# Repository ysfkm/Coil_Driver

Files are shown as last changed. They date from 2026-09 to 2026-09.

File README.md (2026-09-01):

# Coil Driver

## Summary
- Board hosting three independent bi-directional coil drivers (up to 3A each) off a shared +15V supply, using an H-bridge per channel for direction control.
- Setpoints for each channel's analog current control loop are set digitally over a backplane bus (address + data bits → DAC → analog loop); 4-layer 163mm x 100mm PCB.

## Specs
- **Input:** Digital Bus from backplane
  - A0~A7 as addresses
  - D9~D14 as data bits
- **Supply:** An external +15V with 10A rating and +15V from backplane
- **Output:** three bi-directional current up to 3A
- **Description:** Three separate coil drivers each capable of outputting 3A using the same +15V supply to output current. Utilizes digital interface from the backplane to set the setpoints for the analog current control loops separately and uses H-bridge to achieve bi-directional capability.
- **PCB:** 163mm x 100mm / 4 Layer

> **⚠ Note:** When setting a setpoint via the SPI lines, make sure the DIR bits are all driven to the right value since all DIR bits would be updated at the same time, not just the targeted channel for setpoint adjustment.

> **⚠ Note:** For the jumper selecting +15V power supply, make sure either ALL FOUR middle pins are connected or the LEFT AND RIGHT pins are connected, NEVER BOTH.

## Voltage / Nets

| Voltage / Nets | Purpose |
|---|---|
| +15V_EXT | External supply for driving large currents |
| +15V_BP | Backplane supply for regulating voltages and driving small currents |
| +15V | Jumper implemented to choose between +15V_EXT and +15V_BP<br>Drives main op-amp for current output<br>Drives MOSFETs to control H-bridge switching |
| +6V | Regulated from +15_BP, used to regulate +5VA |
| +5VA | Drives DAC and sensing op-amp. Used to generate VREF for DAC |
| +5V | Backplane supply to regulate +3V3 |
| +3V3 | Backplane supply for digital decoder |
| +3V3A | Regulated from +15V_BP, drives DAC |

## Modules

### Root page
- Backplane connector with digital bus, supply, and ground
- This board's own address switch
- Digital decoder latching the data bits when address from A0~A7 matches

### Power Supply page
- Several ferrite beads to connect different ground domains

### DAC
- Takes the three SPI lines and output 0~3V setpoint
- Has four channels, three used for each analog control loop
- Own regulator to precisely generate reference voltage (3V)

### Analog Control pages
All three are basically identical and have the following:
- Main op-amp driving the current
- Setpoint at main op-amp
- Compensator at main op-amp
- Current sense feedback network and voltage amplifier
- H-bridge
- MOSFET gate driver that drives the H-bridge based on DIR bit

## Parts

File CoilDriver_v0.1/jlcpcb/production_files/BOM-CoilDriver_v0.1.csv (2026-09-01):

Comment | Designator | Footprint | LCSC | Quantity
C113280 - SN74LVC573APWR | U17 | C113280-TSSOP-20_L6.5-W4.4-P0.65-LS6.4-BL | C113280 | 1
C114502 - M24C02-FDW | U14 | C114502-SOIC-8_L4.9-W3.9-P1.27-LS6.0-BL | C114502 | 1
10u 16V Tant | C20,C60 | C119051-CASE-A_3216 | C119051 | 2
10 1% | R30,R31,R43,R44,R6,R7 | R_0402_1005Metric | C138066 | 6
10n 50V X7R | C57,C63,C74 | C_0402_1005Metric | C15195 | 3
100p 50V C0G | C11,C23,C29,C37,C46,C67,C78,C8 | C_0402_1005Metric | C1546 | 8
C1554484-DAC8555IPW | U6 | C1554484-TSSOP-16_L5.0-W4.4-P0.65-LS6.4-TL | C1554484 | 1
C157411-LD29150DT50R | U7 | C157411-TO-252-3_L6.5-W5.8-P4.58-BL | C157411 | 1
6.8uH | L8 | C177249-IND-SMD_L5.4-W5.2_FXL0530 | C177249 | 1
C1855802-INA293B2IDBVR | U21,U25,U3 | C1855802-SOT-23-5_L2.9-W1.6-P0.95-LS2.8-BR | C1855802 | 3
C2071868-AP63200WU-7 | U10,U11 | C2071868-SOT-23-6_L2.9-W1.6-P0.95-LS2.8-BR | C2071868 | 2
C207245-SD15C-01FTG | U5 | C207245-SOD-323_L1.7-W1.3-LS2.5-BI-1 | C207245 | 1
22n C0G | C6,C64,C75 | C_0805_2012Metric | C2181592 | 3
C22461594 - PCF8574AP | U15 | C22461594-TSSOP-16_L5.0-W4.4-P0.65-LS6.4-BL-1 | C22461594 | 1
22uH >0.5A | L3,L7 | L_1812_4532Metric | C22469096 | 2
C22469958 - 74LVC1GU04 | U16 | C22469958-SOT-353-5_L2.1-W1.3-P0.65-LS2.3-BL | C22469958 | 1
100 1% | R9 | R_0402_1005Metric | C25076 | 1
R33_Pack | RN3,RN4 | C25508-RES-ARRAY-SMD_0603-8P-L3.2-W1.6-BL | C25508 | 2
C259972-LM1084S-3.3_TR | U20 | C259972-TO-263-3_L8.6-W10.2-P2.54-LS14.4-TL | C259972 | 1
C2653336-74FCT521CTSOG8 | U13 | C2653336-SOIC127P1032X265-20N | C2653336 | 1
C2687965-OPA548FKTWT | U1,U22,U26 | C2687965-TO-263-7_L10.2-W8.9-P1.27-LS15.2-BL | C2687965 | 3
100u 35V Alum | C16 | C2887272-CAP-SMD_BD6.3-L6.6-W6.6-LS7.2-FD_3 | C2887272 | 1
10k 1% | R1,R10,R15,R16,R17,R2,R24,R26,R37,R39,R8 | R_0402_1005Metric | C2906861 | 11
1k 5% | R18,R19,R20,R21,R33,R34,R35,R36,R46,R47,R48,R49 | R_0402_1005Metric | C2906899 | 12
30k 1% | R12 | R_0402_1005Metric | C2909347 | 1
62k 1% | R13 | R_0402_1005Metric | C2909375 | 1
C29718-R10k_Pack04 | RN1,RN2 | C29718-RES-ARRAY-SMD_0603-8P-L3.2-W1.6-BL | C29718 | 2
196k 1% | R11,R14 | R_0402_1005Metric | C3013157 | 2
453k 1% | R28,R4,R41 | R_0402_1005Metric | C3013172 | 3
10u 25V X7R | C10,C13,C19,C2,C21,C3,C30,C32,C33,C34,C40,C41,C42,C43,C49,C58,C68,C70,C71,C79,C81,C82 | C_0805_2012Metric | C3039694 | 22
C306220-826925-6 | J3 | C306220-CONN-TH_12P-P2.54_826925-6 | C306220 | 1
100n 50V X7R | C1,C12,C17,C18,C22,C24,C27,C28,C35,C36,C44,C45,C50,C51,C52,C54,C59,C61,C66,C69,C77,C80,C9 | C_0402_1005Metric | C307331 | 23
1n 50V C0G | C26 | C_0402_1005Metric | C307441 | 1
4k02 1% | R22,R25,R38 | R_0402_1005Metric | C324800 | 3
C3697-WJ2EDGRC-5.08-02P-14-00A | CN1,CN3,CN5,CN7 | C3697-CONN-TH_2P-P5.08_WJ2EDGRC-5.08-2P | C3697 | 4
100u 16V Alum | C31 | C37308-CAP-SMD_BD6.3-L6.6-W6.6-LS7.2-FD | C37308 | 1
2200u 35V Alum | C15,C4,C72,C83 | C3829879-CAP-SMD_BD16.0-L17.0-W17.0-LS18.0-FD | C3829879 | 4
C458084-DS-08RP | SW1 | C458084-SW-TH_DS-08RP | C458084 | 1
Conn_01x02 | J2 | C492401-HDR-TH_2P-P2.54-V-M | C492401 | 1
C506609-SISS27DN-T1-GE3 | U2 | C506609-POWERPAK-1212-8_L3.3-W3.3-P0.65-BL-EP | C506609 | 1
C50793 - NC7WZ14P6X | U12 | C50793-SC-70-6_L2.2-W1.3-P0.65-LS2.2-BR | C50793 | 1
C511854-SS54SMB | D1,D10,D11,D12,D13,D14,D15,D2,D3,D4,D5,D6,D7,D8,D9 | C511854-SMB_L4.6-W3.6-LS5.3-RD | C511854 | 15
C5173361-DIN41612-CONN-TH_96P | J1 | C5173361-DIN41612-96P | C5173361 | 1
33uH | L2 | L_0603_1608Metric | C5339211 | 1
10uH | L5 | C540965-IND-SMD_L6.5-W6.5_VISHAY | C540965 | 1
C550069-BZB784-C15,115 | U23,U27,U4 | C550069-SOT-323-3_L2.0-W1.3-P1.30-LS2.1-BR | C550069 | 3
C637542-MIC4428YM | U19,U24,U28 | C637542-SOIC-8_L4.9-W3.9-P1.27-LS6.0-BL | C637542 | 3
C659573-ADR443BRZ-REEL7 | U8 | C659573-SOIC-8_L4.9-W3.9-P1.27-LS6.0-BL | C659573 | 1
C71370-WJ2EDGK-5.08-02P-14-00A | CN2,CN4,CN6,CN8 | C71370-FL_001 | C71370 | 4
C7220836-BSC010N04LS6ATMA1 | T1,T10,T11,T12,T2,T3,T4,T5,T6,T7,T8,T9 | C7220836-TDSON-8_L6.0-W5.0-P1.27-LS6.2-BL_1 | C7220836 | 12
3.3u 25V X7R | C65,C7,C76 | C_0805_2012Metric | C7393948 | 3
0.02 1W 1% | R32,R45,R5 | R_1206_3216Metric | C7420010 | 3
22u 16V X7R | C38,C39 | C_1206_3216Metric | C7472972 | 2
1u 10V X7R | C25,C53,C55,C56 | C_0402_1005Metric | C7500381 | 4
C7835-SN74LVC1G14DBVR | U18 | C7835-SOT-23-5_L3.0-W1.7-P0.95-LS2.8-BR | C7835 | 1
22uH | L6,L9 | C842901-IND-SMD_L7.0-W6.6 | C842901 | 2
C85832-BLM18KG331SN1D | L1,L10,L4 | C85832-L0603 | C85832 | 3
15p 50V C0G | C14 | C_0402_1005Metric | C880657 | 1
C907854-SD12C | U9 | C907854-SOD-323_L1.7-W1.3-LS2.5-BI | C907854 | 1
22u 10V X7R | C47,C48 | C_0805_2012Metric | C907991 | 2
C965863-XL-1606UGC | D29 | C965863-LED-SMD_L1.7-W1.1-R-RD_ORANGE | C965863 | 1

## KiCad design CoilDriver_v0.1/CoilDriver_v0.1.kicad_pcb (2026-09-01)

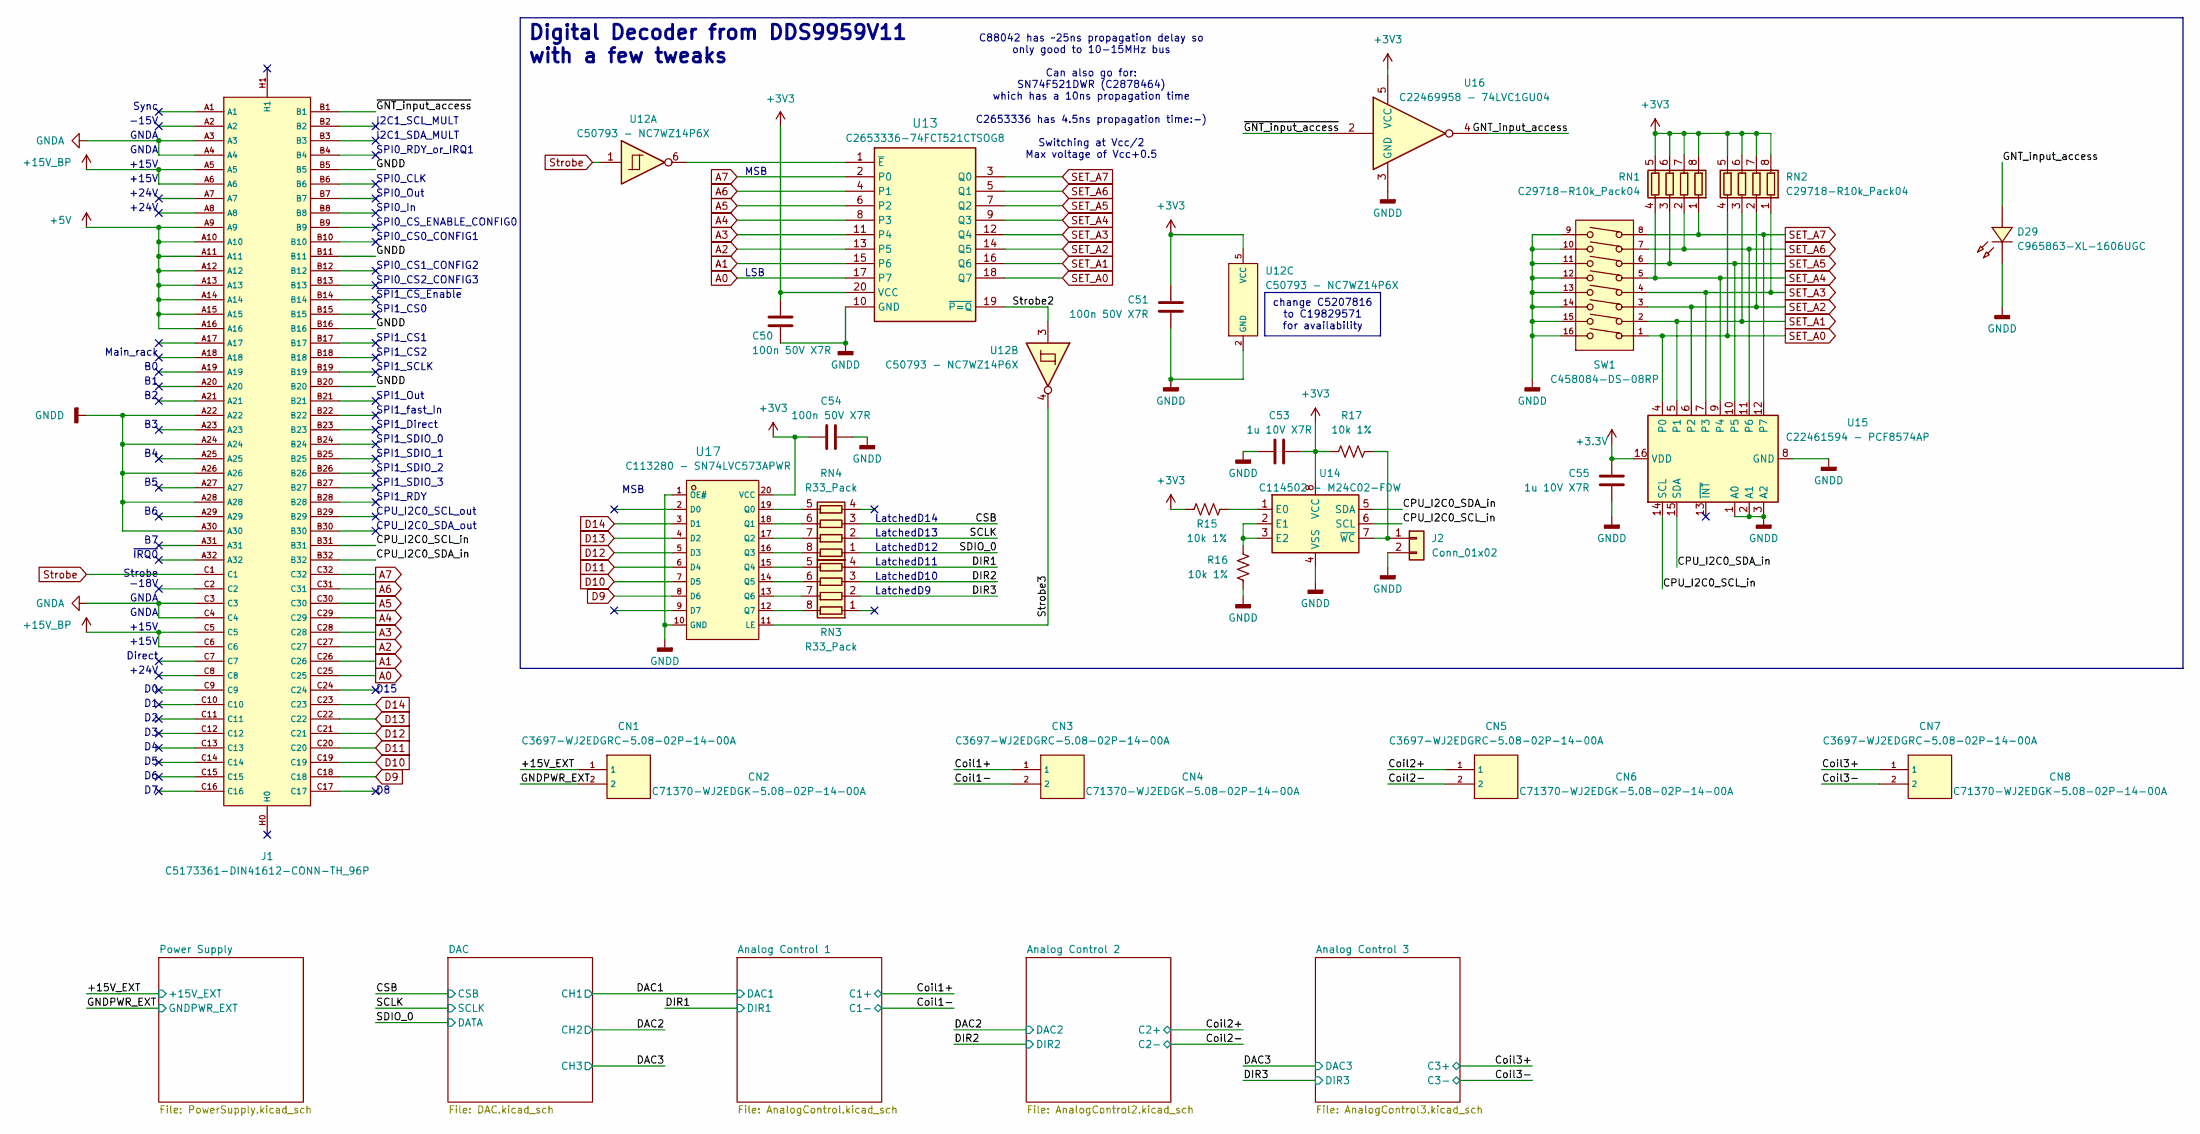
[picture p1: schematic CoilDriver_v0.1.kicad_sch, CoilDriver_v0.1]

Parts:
C50, C51, C54: 100n 50V X7R; C_0402_1005Metric; LCSC C307331
C53, C55: 1u 10V X7R; C_0402_1005Metric; LCSC C7500381
CN1, CN3, CN5, CN7: C3697-WJ2EDGRC-5.08-02P-14-00A; C3697-CONN-TH_2P-P5.08_WJ2EDGRC-5.08-2P; LCSC C3697
CN2, CN4, CN6, CN8: C71370-WJ2EDGK-5.08-02P-14-00A; C71370-FL_001; LCSC C71370
D29: C965863-XL-1606UGC; C965863-LED-SMD_L1.7-W1.1-R-RD_ORANGE; LCSC C965863
J1: C5173361-DIN41612-CONN-TH_96P; C5173361-DIN41612-96P; LCSC C5173361
J2: Conn_01x02; C492401-HDR-TH_2P-P2.54-V-M; LCSC C492401
R15, R16, R17: 10k 1%; R_0402_1005Metric; LCSC C2906861
RN1, RN2: C29718-R10k_Pack04; C29718-RES-ARRAY-SMD_0603-8P-L3.2-W1.6-BL; LCSC C29718
RN3, RN4: R33_Pack; C25508-RES-ARRAY-SMD_0603-8P-L3.2-W1.6-BL; LCSC C25508
SW1: C458084-DS-08RP; C458084-SW-TH_DS-08RP; LCSC C458084
U12: C50793 - NC7WZ14P6X; C50793-SC-70-6_L2.2-W1.3-P0.65-LS2.2-BR; LCSC C50793
U13: C2653336-74FCT521CTSOG8; C2653336-SOIC127P1032X265-20N; LCSC C2653336
U14: C114502 - M24C02-FDW; C114502-SOIC-8_L4.9-W3.9-P1.27-LS6.0-BL; LCSC C114502
U15: C22461594 - PCF8574AP; C22461594-TSSOP-16_L5.0-W4.4-P0.65-LS6.4-BL-1; LCSC C22461594
U16: C22469958 - 74LVC1GU04; C22469958-SOT-353-5_L2.1-W1.3-P0.65-LS2.3-BL; LCSC C22469958
U17: C113280 - SN74LVC573APWR; C113280-TSSOP-20_L6.5-W4.4-P0.65-LS6.4-BL; LCSC C113280

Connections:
+3.3V: C55.1, U15.16 (VDD)
+3V3: C50.1, C51.1, C53.1, C54.1, R15.1, R17.1, RN1.5 (R4.2), RN1.6 (R3.2), RN1.7 (R2.2), RN1.8 (R1.2), RN2.5 (R4.2), RN2.6 (R3.2), RN2.7 (R2.2), RN2.8 (R1.2), U12.5 (VCC), U13.20 (VCC), U14.8 (VCC), U16.5 (VCC), U17.20 (VCC); also elsewhere on the board
+5V: J1.A9, J1.A10, J1.A11, J1.A12, J1.A13, J1.A14, J1.A15, J1.A16; also elsewhere on the board
+15V_BP: J1.A5, J1.A6, J1.C5, J1.C6; also elsewhere on the board
/+15V_EXT: CN1.1; also elsewhere on the board
/CPU_I2C0_SCL_in: J1.B31, U14.6 (SCL), U15.14 (SCL)
/CPU_I2C0_SDA_in: J1.B32, U14.5 (SDA), U15.15 (SDA)
/CSB: RN4.3 (R3.1); also elsewhere on the board
/Coil1+: CN3.1; also elsewhere on the board
/Coil1-: CN3.2; also elsewhere on the board
/Coil2+: CN5.1; also elsewhere on the board
/Coil2-: CN5.2; also elsewhere on the board
/Coil3+: CN7.1; also elsewhere on the board
/Coil3-: CN7.2; also elsewhere on the board
/DIR1: RN3.4 (R4.1); also elsewhere on the board
/DIR2: RN3.3 (R3.1); also elsewhere on the board
/DIR3: RN3.2 (R2.1); also elsewhere on the board
/GNT_input_access: D29.2 (A), U16.4
/SCLK: RN4.2 (R2.1); also elsewhere on the board
/SDIO_0: RN4.1 (R1.1); also elsewhere on the board
/Strobe2: U12.3, U13.19 (~P=Q)
/Strobe3: U12.4, U17.11 (LE)
/~GNT_input_access: J1.B1, U16.2
A0: J1.C25, U13.17 (P7)
A1: J1.C26, U13.15 (P6)
A2: J1.C27, U13.13 (P5)
A3: J1.C28, U13.11 (P4)
A4: J1.C29, U13.8 (P3)
A5: J1.C30, U13.6 (P2)
A6: J1.C31, U13.4 (P1)
A7: J1.C32, U13.2 (P0)
D9: J1.C18, U17.8 (D6)
D10: J1.C19, U17.7 (D5)
D11: J1.C20, U17.6 (D4)
D12: J1.C21, U17.5 (D3)
D13: J1.C22, U17.4 (D2)
D14: J1.C23, U17.3 (D1)
GNDA: J1.A3, J1.A4, J1.C3, J1.C4; also elsewhere on the board
GNDD: C50.2, C51.2, C53.2, C54.2, C55.2, D29.1 (K), J1.A22, J1.A24, J1.A26, J1.A28, J1.A30, J1.B5, J1.B11, J1.B16, J1.B20, J2.2, R16.2, SW1.9, SW1.10, SW1.11, SW1.12, SW1.13, SW1.14, SW1.15, SW1.16, U12.2 (GND), U13.10 (GND), U14.4 (VSS), U15.1 (A0), U15.2 (A1), U15.3 (A2), U15.8 (GND), U16.3 (GND), U17.1 (OE#), U17.10 (GND); also elsewhere on the board
GNDPWR: CN1.2; also elsewhere on the board
unnamed: J2.1, R17.2, U14.7 (~WC)
unnamed: RN3.8 (R1.2), U17.12 (Q7)
unnamed: RN3.7 (R2.2), U17.13 (Q6)
unnamed: RN3.6 (R3.2), U17.14 (Q5)
unnamed: RN3.5 (R4.2), U17.15 (Q4)
unnamed: RN4.8 (R1.2), U17.16 (Q3)
unnamed: RN4.7 (R2.2), U17.17 (Q2)
unnamed: RN4.6 (R3.2), U17.18 (Q1)
unnamed: RN4.5 (R4.2), U17.19 (Q0)
unnamed: U12.6, U13.1 (~E)
unnamed: R15.2, U14.1 (E0)
unnamed: R16.1, U14.2 (E1), U14.3 (E2)
SET_A0: RN2.4 (R4.1), SW1.1, U13.18 (Q7), U15.4 (P0)
SET_A1: RN2.3 (R3.1), SW1.2, U13.16 (Q6), U15.5 (P1)
SET_A2: RN2.2 (R2.1), SW1.3, U13.14 (Q5), U15.6 (P2)
SET_A3: RN2.1 (R1.1), SW1.4, U13.12 (Q4), U15.7 (P3)
SET_A4: RN1.4 (R4.1), SW1.5, U13.9 (Q3), U15.9 (P4)
SET_A5: RN1.3 (R3.1), SW1.6, U13.7 (Q2), U15.10 (P5)
SET_A6: RN1.2 (R2.1), SW1.7, U13.5 (Q1), U15.11 (P6)
SET_A7: RN1.1 (R1.1), SW1.8, U13.3 (Q0), U15.12 (P7)
Strobe: J1.C1, U12.1

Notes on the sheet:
Main_rack
CPU_I2C0_SCL_out
SPI1_Direct
SPI0_CS2_CONFIG3
+24V
SPI0_CS_ENABLE_CONFIG0
+15V
SPI0_In
LatchedD14
Strobe
SPI1_CS1
SPI1_SCLK
SPI1_SDIO_2
SPI1_SDIO_3
SPI1_Out
Direct
GNDA
-18V
SPI1_SDIO_1
LatchedD11
CPU_I2C0_SDA_out
MSB
Sync
~{IRQ0}
LatchedD9
SPI0_CLK
D15
SPI0_Out
LSB
LatchedD10
SPI0_CS1_CONFIG2
SPI1_CS0
LatchedD13
SPI1_CS2
~{SPI1_CS_Enable}
SPI0_RDY_or_IRQ1
C88042 has ~25ns propagation delay so only good to 10-15MHz bus Can also go for: SN74F521DWR (C2878464) which has a 10ns propagation time C2653336 has 4.5ns propagation time:-) Switching at Vcc/2 Max voltage of Vcc+0.5
I2C1_SCL_MULT
I2C1_SDA_MULT
SPI1_SDIO_0

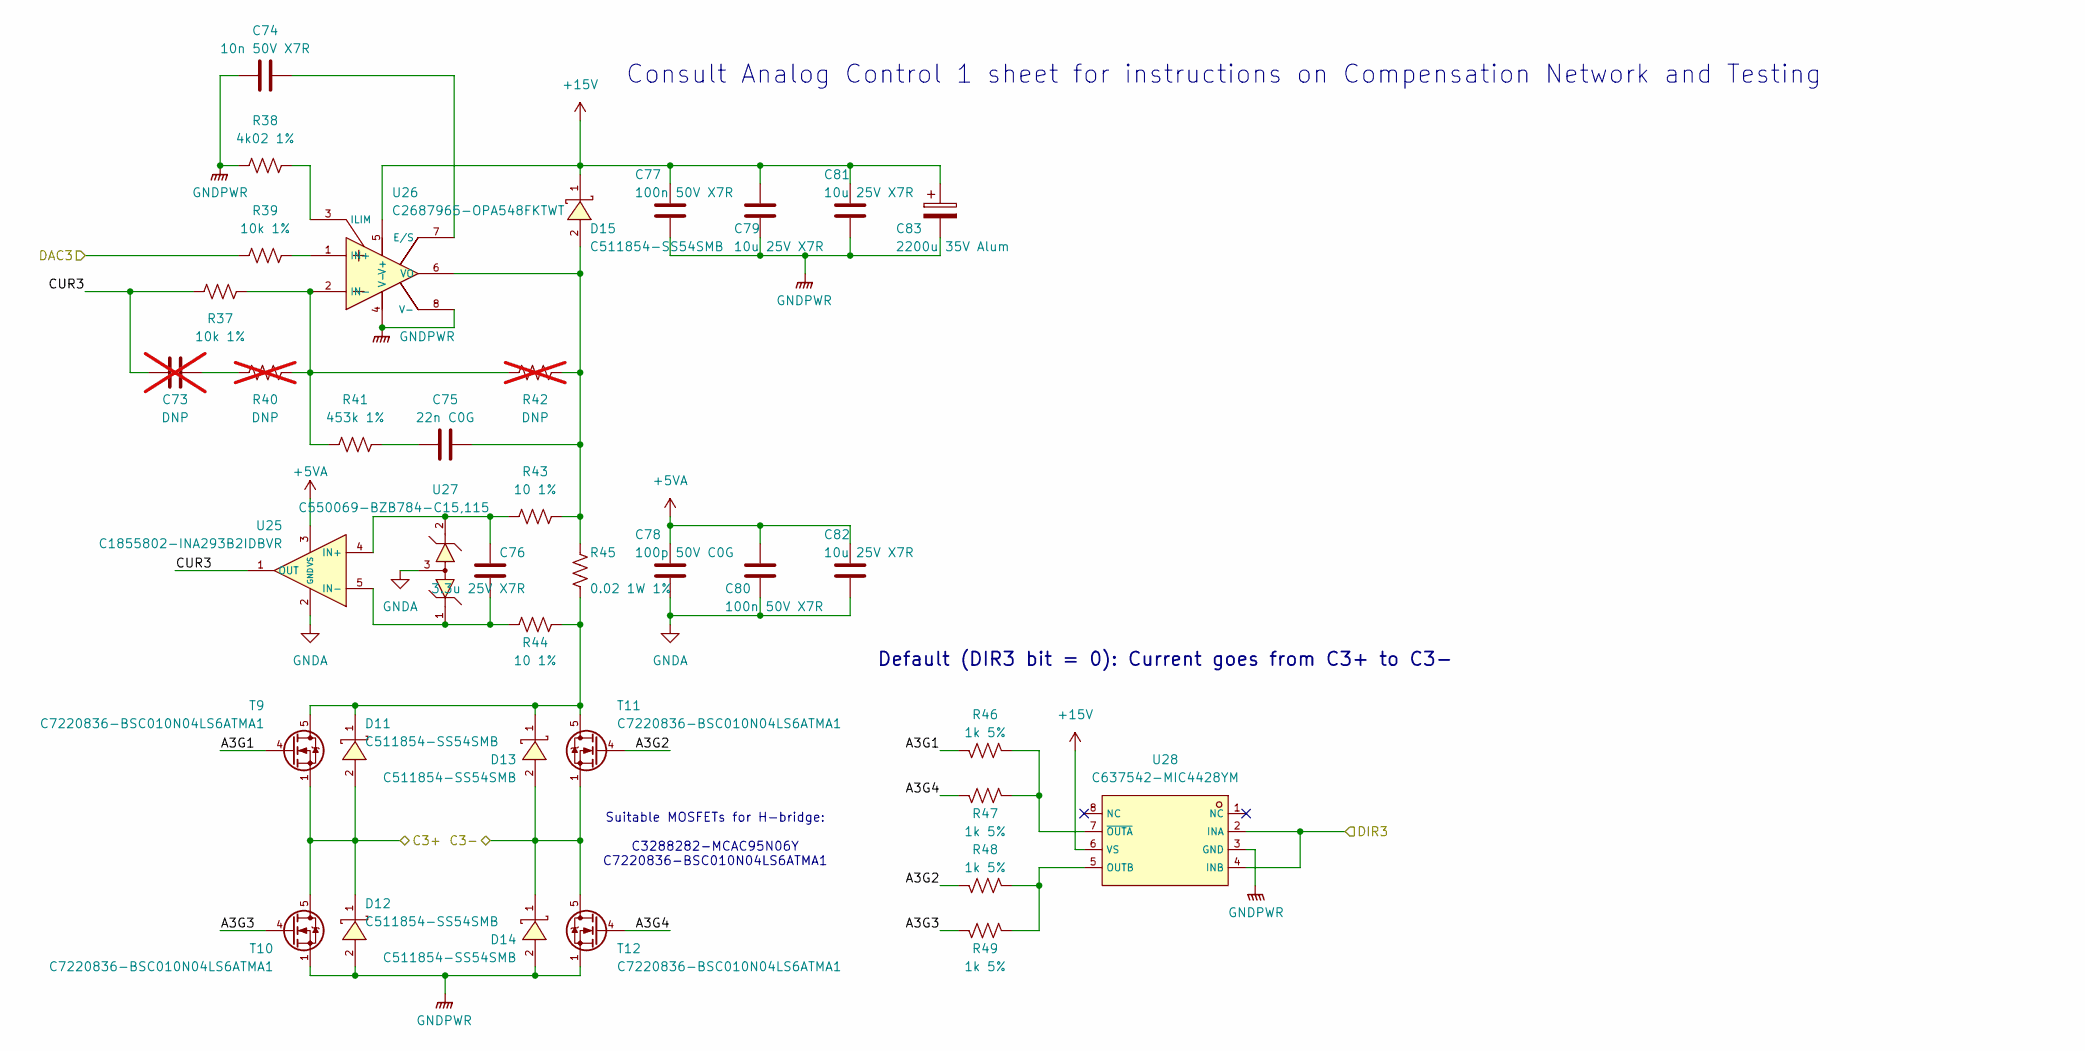
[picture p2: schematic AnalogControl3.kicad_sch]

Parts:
C73: DNP; C_0805_2012Metric; not fitted
C74: 10n 50V X7R; C_0402_1005Metric; LCSC C15195
C75: 22n C0G; C_0805_2012Metric; LCSC C2181592
C76: 3.3u 25V X7R; C_0805_2012Metric; LCSC C7393948
C77, C80: 100n 50V X7R; C_0402_1005Metric; LCSC C307331
C78: 100p 50V C0G; C_0402_1005Metric; LCSC C1546
C79, C81, C82: 10u 25V X7R; C_0805_2012Metric; LCSC C3039694
C83: 2200u 35V Alum; C3829879-CAP-SMD_BD16.0-L17.0-W17.0-LS18.0-FD; LCSC C3829879
D11, D12, D13, D14, D15: C511854-SS54SMB; C511854-SMB_L4.6-W3.6-LS5.3-RD; LCSC C511854
R37, R39: 10k 1%; R_0402_1005Metric; LCSC C2906861
R38: 4k02 1%; R_0402_1005Metric; LCSC C324800
R40, R42: DNP; R_0603_1608Metric; not fitted
R41: 453k 1%; R_0402_1005Metric; LCSC C3013172
R43, R44: 10 1%; R_0402_1005Metric; LCSC C138066
R45: 0.02 1W 1%; R_1206_3216Metric; LCSC C7420010
R46, R47, R48, R49: 1k 5%; R_0402_1005Metric; LCSC C2906899
T9, T10, T11, T12: C7220836-BSC010N04LS6ATMA1; C7220836-TDSON-8_L6.0-W5.0-P1.27-LS6.2-BL_1; LCSC C7220836
U25: C1855802-INA293B2IDBVR; C1855802-SOT-23-5_L2.9-W1.6-P0.95-LS2.8-BR; LCSC C1855802
U26: C2687965-OPA548FKTWT; C2687965-TO-263-7_L10.2-W8.9-P1.27-LS15.2-BL; LCSC C2687965
U27: C550069-BZB784-C15,115; C550069-SOT-323-3_L2.0-W1.3-P1.30-LS2.1-BR; LCSC C550069
U28: C637542-MIC4428YM; C637542-SOIC-8_L4.9-W3.9-P1.27-LS6.0-BL; LCSC C637542

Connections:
+5VA: C78.1, C80.1, C82.1, U25.3 (VS); also elsewhere on the board
+15V: C77.1, C79.1, C81.1, C83.1, D15.1 (K), U26.5 (V+), U28.6 (VS); also elsewhere on the board
/Analog Control 3/A3G1: R46.2, T9.4 (G)
/Analog Control 3/A3G2: R48.2, T11.4 (G)
/Analog Control 3/A3G3: R49.2, T10.4 (G)
/Analog Control 3/A3G4: R47.2, T12.4 (G)
/Analog Control 3/CUR3: C73.1, R37.1, U25.1 (OUT)
/Coil3+: D11.2 (A), D12.1 (K), T9.1 (S), T10.5 (D); also elsewhere on the board
/Coil3-: D13.2 (A), D14.1 (K), T11.1 (S), T12.5 (D); also elsewhere on the board
/DAC3: R39.1; also elsewhere on the board
/DIR3: U28.2 (INA), U28.4 (INB); also elsewhere on the board
GNDA: C78.2, C80.2, C82.2, U25.2 (GND), U27.3; also elsewhere on the board
GNDPWR: C74.1, C77.2, C79.2, C81.2, C83.2, D12.2 (A), D14.2 (A), R38.1, T10.1 (S), T12.1 (S), U26.4 (V-), U26.8 (V-), U28.3 (GND); also elsewhere on the board
unnamed: C73.2, R40.1
unnamed: C75.1, R41.2
unnamed: D11.1 (K), D13.1 (K), R44.1, R45.1, T9.5 (D), T11.5 (D)
unnamed: C75.2, D15.2 (A), R42.2, R43.1, R45.2, U26.6 (VO)
unnamed: C76.2, R43.2, U25.4 (IN+), U27.2
unnamed: C76.1, R44.2, U25.5 (IN-), U27.1
unnamed: C74.2, U26.7 (E/S)
unnamed: R38.2, U26.3 (ILIM)
unnamed: R39.2, U26.1 (IN+)
unnamed: R37.2, R40.2, R41.1, R42.1, U26.2 (IN-)
unnamed: R48.1, R49.1, U28.5 (OUTB)
unnamed: R46.1, R47.1, U28.7 (~OUTA)

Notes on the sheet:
Consult Analog Control 1 sheet for instructions on Compensation Network and Testing
Default (DIR3 bit = 0): Current goes from C3+ to C3-
Suitable MOSFETs for H-bridge: C3288282-MCAC95N06Y C7220836-BSC010N04LS6ATMA1

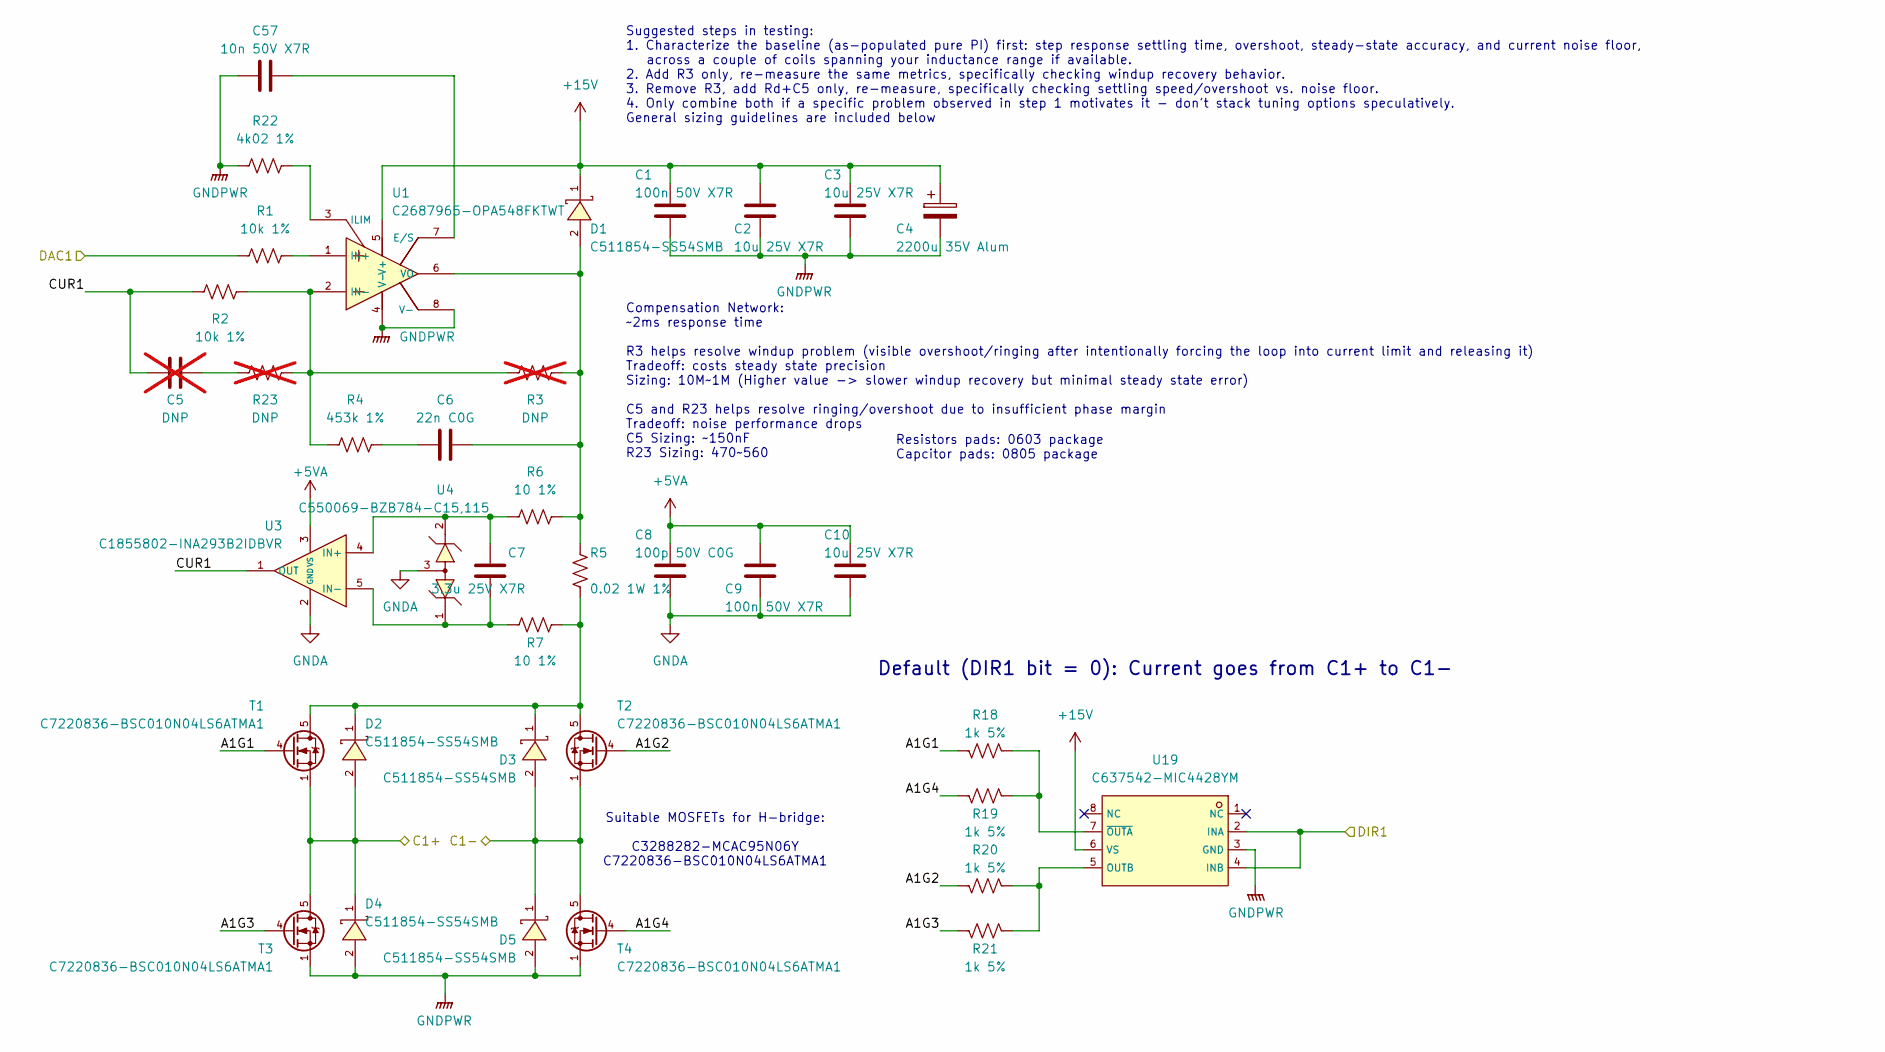
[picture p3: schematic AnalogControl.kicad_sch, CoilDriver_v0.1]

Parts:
C1, C9: 100n 50V X7R; C_0402_1005Metric; LCSC C307331
C2, C3, C10: 10u 25V X7R; C_0805_2012Metric; LCSC C3039694
C4: 2200u 35V Alum; C3829879-CAP-SMD_BD16.0-L17.0-W17.0-LS18.0-FD; LCSC C3829879
C5: DNP; C_0805_2012Metric; not fitted
C6: 22n C0G; C_0805_2012Metric; LCSC C2181592
C7: 3.3u 25V X7R; C_0805_2012Metric; LCSC C7393948
C8: 100p 50V C0G; C_0402_1005Metric; LCSC C1546
C57: 10n 50V X7R; C_0402_1005Metric; LCSC C15195
D1, D2, D3, D4, D5: C511854-SS54SMB; C511854-SMB_L4.6-W3.6-LS5.3-RD; LCSC C511854
R1, R2: 10k 1%; R_0402_1005Metric; LCSC C2906861
R3, R23: DNP; R_0603_1608Metric; not fitted
R4: 453k 1%; R_0402_1005Metric; LCSC C3013172
R5: 0.02 1W 1%; R_1206_3216Metric; LCSC C7420010
R6, R7: 10 1%; R_0402_1005Metric; LCSC C138066
R18, R19, R20, R21: 1k 5%; R_0402_1005Metric; LCSC C2906899
R22: 4k02 1%; R_0402_1005Metric; LCSC C324800
T1, T2, T3, T4: C7220836-BSC010N04LS6ATMA1; C7220836-TDSON-8_L6.0-W5.0-P1.27-LS6.2-BL_1; LCSC C7220836
U1: C2687965-OPA548FKTWT; C2687965-TO-263-7_L10.2-W8.9-P1.27-LS15.2-BL; LCSC C2687965
U3: C1855802-INA293B2IDBVR; C1855802-SOT-23-5_L2.9-W1.6-P0.95-LS2.8-BR; LCSC C1855802
U4: C550069-BZB784-C15,115; C550069-SOT-323-3_L2.0-W1.3-P1.30-LS2.1-BR; LCSC C550069
U19: C637542-MIC4428YM; C637542-SOIC-8_L4.9-W3.9-P1.27-LS6.0-BL; LCSC C637542

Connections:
+5VA: C8.1, C9.1, C10.1, U3.3 (VS); also elsewhere on the board
+15V: C1.1, C2.1, C3.1, C4.1, D1.1 (K), U1.5 (V+), U19.6 (VS); also elsewhere on the board
/Analog Control 1/A1G1: R18.2, T1.4 (G)
/Analog Control 1/A1G2: R20.2, T2.4 (G)
/Analog Control 1/A1G3: R21.2, T3.4 (G)
/Analog Control 1/A1G4: R19.2, T4.4 (G)
/Analog Control 1/CUR1: C5.1, R2.1, U3.1 (OUT)
/Coil1+: D2.2 (A), D4.1 (K), T1.1 (S), T3.5 (D); also elsewhere on the board
/Coil1-: D3.2 (A), D5.1 (K), T2.1 (S), T4.5 (D); also elsewhere on the board
/DAC1: R1.1; also elsewhere on the board
/DIR1: U19.2 (INA), U19.4 (INB); also elsewhere on the board
GNDA: C8.2, C9.2, C10.2, U3.2 (GND), U4.3; also elsewhere on the board
GNDPWR: C1.2, C2.2, C3.2, C4.2, C57.1, D4.2 (A), D5.2 (A), R22.1, T3.1 (S), T4.1 (S), U1.4 (V-), U1.8 (V-), U19.3 (GND); also elsewhere on the board
unnamed: C5.2, R23.1
unnamed: C6.1, R4.2
unnamed: C6.2, D1.2 (A), R3.2, R5.2, R6.1, U1.6 (VO)
unnamed: D2.1 (K), D3.1 (K), R5.1, R7.1, T1.5 (D), T2.5 (D)
unnamed: C57.2, U1.7 (E/S)
unnamed: R22.2, U1.3 (ILIM)
unnamed: R1.2, U1.1 (IN+)
unnamed: R2.2, R3.1, R4.1, R23.2, U1.2 (IN-)
unnamed: C7.2, R6.2, U3.4 (IN+), U4.2
unnamed: C7.1, R7.2, U3.5 (IN-), U4.1
unnamed: R20.1, R21.1, U19.5 (OUTB)
unnamed: R18.1, R19.1, U19.7 (~OUTA)

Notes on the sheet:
Default (DIR1 bit = 0): Current goes from C1+ to C1-
Suitable MOSFETs for H-bridge: C3288282-MCAC95N06Y C7220836-BSC010N04LS6ATMA1
Suggested steps in testing: 1. Characterize the baseline (as-populated pure PI) first: step response settling time, overshoot, steady-state accuracy, and current noise floor, across a couple of coils spanning your inductance range if available. 2. Add R3 only, re-measure the same metrics, specifica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
Compensation Network: ~2ms response time R3 helps resolve windup problem (visible overshoot/ringing after intentionally forcing the loop into current limit and releasing it) Tradeoff: costs steady state precision Sizing: 10M~1M (Higher value -> slower windup recovery but minimal steady state error)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
Resistors pads: 0603 package Capcitor pads: 0805 package

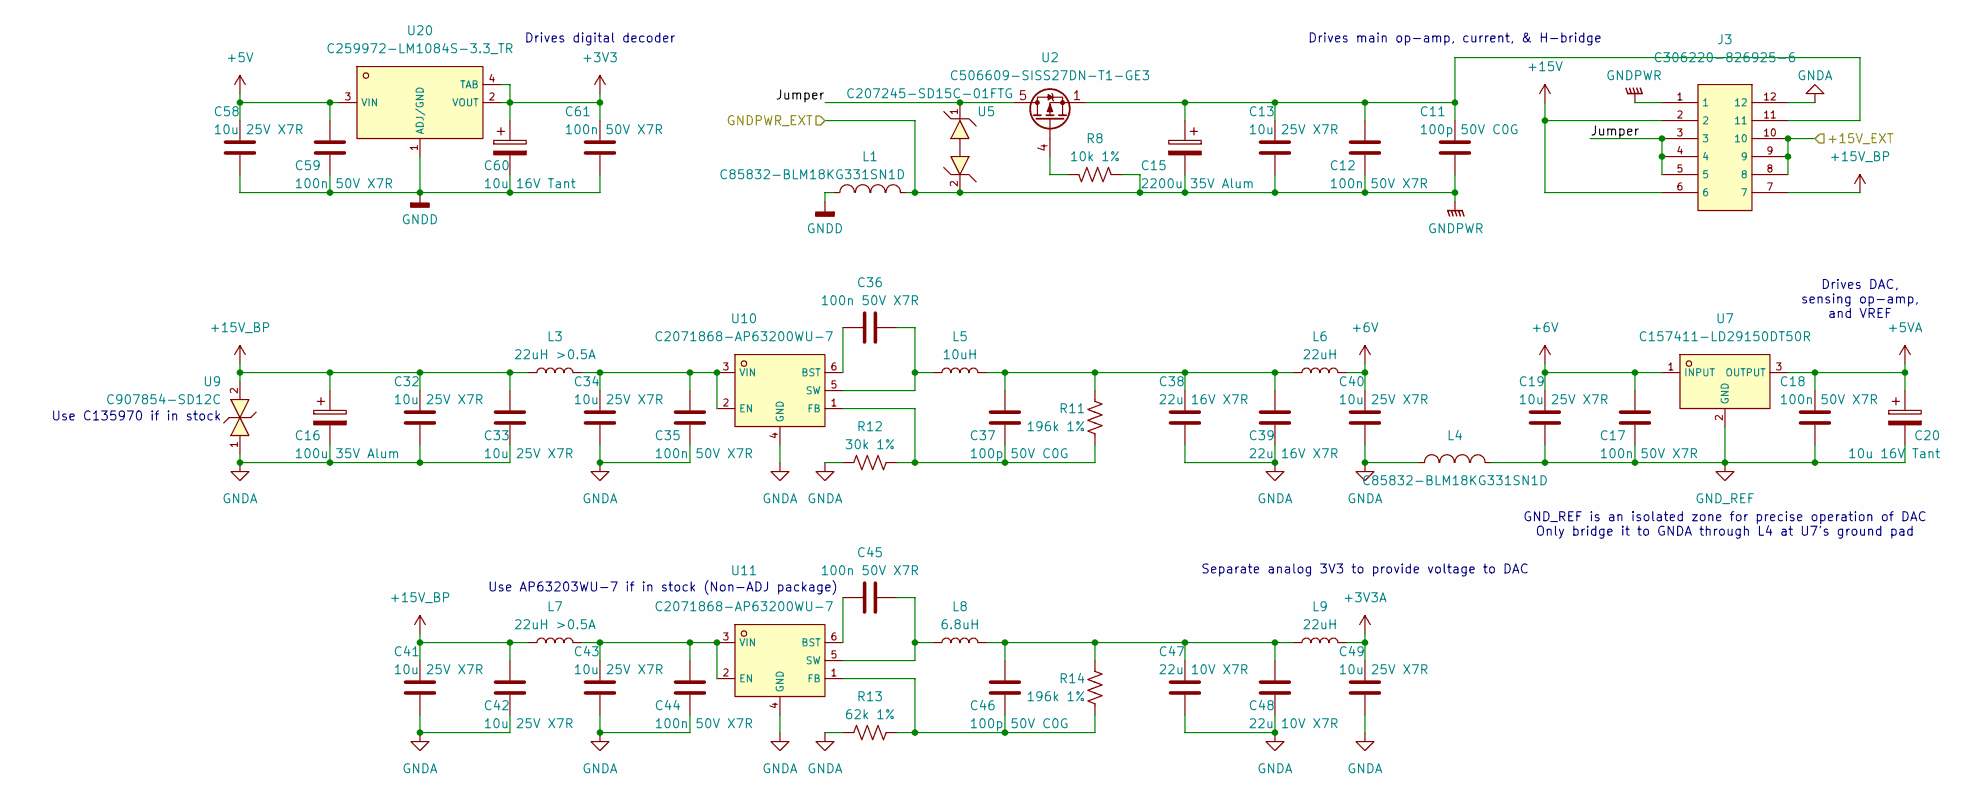
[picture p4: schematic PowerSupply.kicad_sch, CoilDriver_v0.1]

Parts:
C11, C37, C46: 100p 50V C0G; C_0402_1005Metric; LCSC C1546
C12, C17, C18, C35, C36, C44, C45, C59, C61: 100n 50V X7R; C_0402_1005Metric; LCSC C307331
C13, C19, C32, C33, C34, C40, C41, C42, C43, C49, C58: 10u 25V X7R; C_0805_2012Metric; LCSC C3039694
C15: 2200u 35V Alum; C3829879-CAP-SMD_BD16.0-L17.0-W17.0-LS18.0-FD; LCSC C3829879
C16: 100u 35V Alum; C2887272-CAP-SMD_BD6.3-L6.6-W6.6-LS7.2-FD_3; LCSC C2887272
C20, C60: 10u 16V Tant; C119051-CASE-A_3216; LCSC C119051
C38, C39: 22u 16V X7R; C_1206_3216Metric; LCSC C7472972
C47, C48: 22u 10V X7R; C_0805_2012Metric; LCSC C907991
J3: C306220-826925-6; C306220-CONN-TH_12P-P2.54_826925-6; LCSC C306220
L1, L4: C85832-BLM18KG331SN1D; C85832-L0603; LCSC C85832
L3, L7: 22uH >0.5A; L_1812_4532Metric; LCSC C22469096
L5: 10uH; C540965-IND-SMD_L6.5-W6.5_VISHAY; LCSC C540965
L6, L9: 22uH; C842901-IND-SMD_L7.0-W6.6; LCSC C842901
L8: 6.8uH; C177249-IND-SMD_L5.4-W5.2_FXL0530; LCSC C177249
R8: 10k 1%; R_0402_1005Metric; LCSC C2906861
R11, R14: 196k 1%; R_0402_1005Metric; LCSC C3013157
R12: 30k 1%; R_0402_1005Metric; LCSC C2909347
R13: 62k 1%; R_0402_1005Metric; LCSC C2909375
U2: C506609-SISS27DN-T1-GE3; C506609-POWERPAK-1212-8_L3.3-W3.3-P0.65-BL-EP; LCSC C506609
U5: C207245-SD15C-01FTG; C207245-SOD-323_L1.7-W1.3-LS2.5-BI-1; LCSC C207245
U7: C157411-LD29150DT50R; C157411-TO-252-3_L6.5-W5.8-P4.58-BL; LCSC C157411
U9: C907854-SD12C; C907854-SOD-323_L1.7-W1.3-LS2.5-BI; LCSC C907854
U10, U11: C2071868-AP63200WU-7; C2071868-SOT-23-6_L2.9-W1.6-P0.95-LS2.8-BR; LCSC C2071868
U20: C259972-LM1084S-3.3_TR; C259972-TO-263-3_L8.6-W10.2-P2.54-LS14.4-TL; LCSC C259972

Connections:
+3V3: C60.1, C61.1, U20.2 (VOUT), U20.4 (TAB); also elsewhere on the board
+3V3A: C49.1, L9.2; also elsewhere on the board
+5V: C58.1, C59.1, U20.3 (VIN); also elsewhere on the board
+5VA: C18.1, C20.1, U7.3 (OUTPUT); also elsewhere on the board
+6V: C17.1, C19.1, C40.1, L6.2, U7.1 (INPUT)
+15V: J3.2, J3.6; also elsewhere on the board
+15V_BP: C16.1, C32.1, C33.1, C41.1, C42.1, J3.7, L3.1, L7.1, U9.2; also elsewhere on the board
/+15V_EXT: J3.8, J3.9, J3.10; also elsewhere on the board
/Power Supply/Jumper: J3.3, J3.4, J3.5, U2.5 (D), U2.6 (D), U2.7 (D), U2.8 (D), U2.9 (D), U5.1
GNDA: C16.2, C32.2, C33.2, C34.2, C35.2, C38.2, C39.2, C40.2, C41.2, C42.2, C43.2, C44.2, C47.2, C48.2, C49.2, J3.12, L4.1, R12.1, R13.1, U9.1, U10.4 (GND), U11.4 (GND); also elsewhere on the board
GNDD: C58.2, C59.2, C60.2, C61.2, L1.2, U20.1 (ADJ/GND); also elsewhere on the board
GNDPWR: C11.2, C12.2, C13.2, C15.2, J3.1, L1.1, R8.1, U5.2; also elsewhere on the board
GND_REF: C17.2, C18.2, C19.2, C20.2, L4.2, U7.2 (GND); also elsewhere on the board
unnamed: C11.1, C12.1, C13.1, C15.1, J3.11, U2.1 (S), U2.2 (S), U2.3 (S)
unnamed: C37.1, C38.1, C39.1, L5.2, L6.1, R11.2
unnamed: C46.1, C47.1, C48.1, L8.2, L9.1, R14.2
unnamed: R8.2, U2.4 (G)
unnamed: C36.1, U10.6 (BST)
unnamed: C34.1, C35.1, L3.2, U10.2 (EN), U10.3 (VIN)
unnamed: C37.2, R11.1, R12.2, U10.1 (FB)
unnamed: C36.2, L5.1, U10.5 (SW)
unnamed: C45.1, U11.6 (BST)
unnamed: C43.1, C44.1, L7.2, U11.2 (EN), U11.3 (VIN)
unnamed: C46.2, R13.2, R14.1, U11.1 (FB)
unnamed: C45.2, L8.1, U11.5 (SW)

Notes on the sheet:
Drives digital decoder
Drives main op-amp, current, & H-bridge
Drives DAC, sensing op-amp, and VREF
GND_REF is an isolated zone for precise operation of DAC Only bridge it to GNDA through L4 at U7's ground pad
Use C135970 if in stock
Separate analog 3V3 to provide voltage to DAC
Use AP63203WU-7 if in stock (Non-ADJ package)

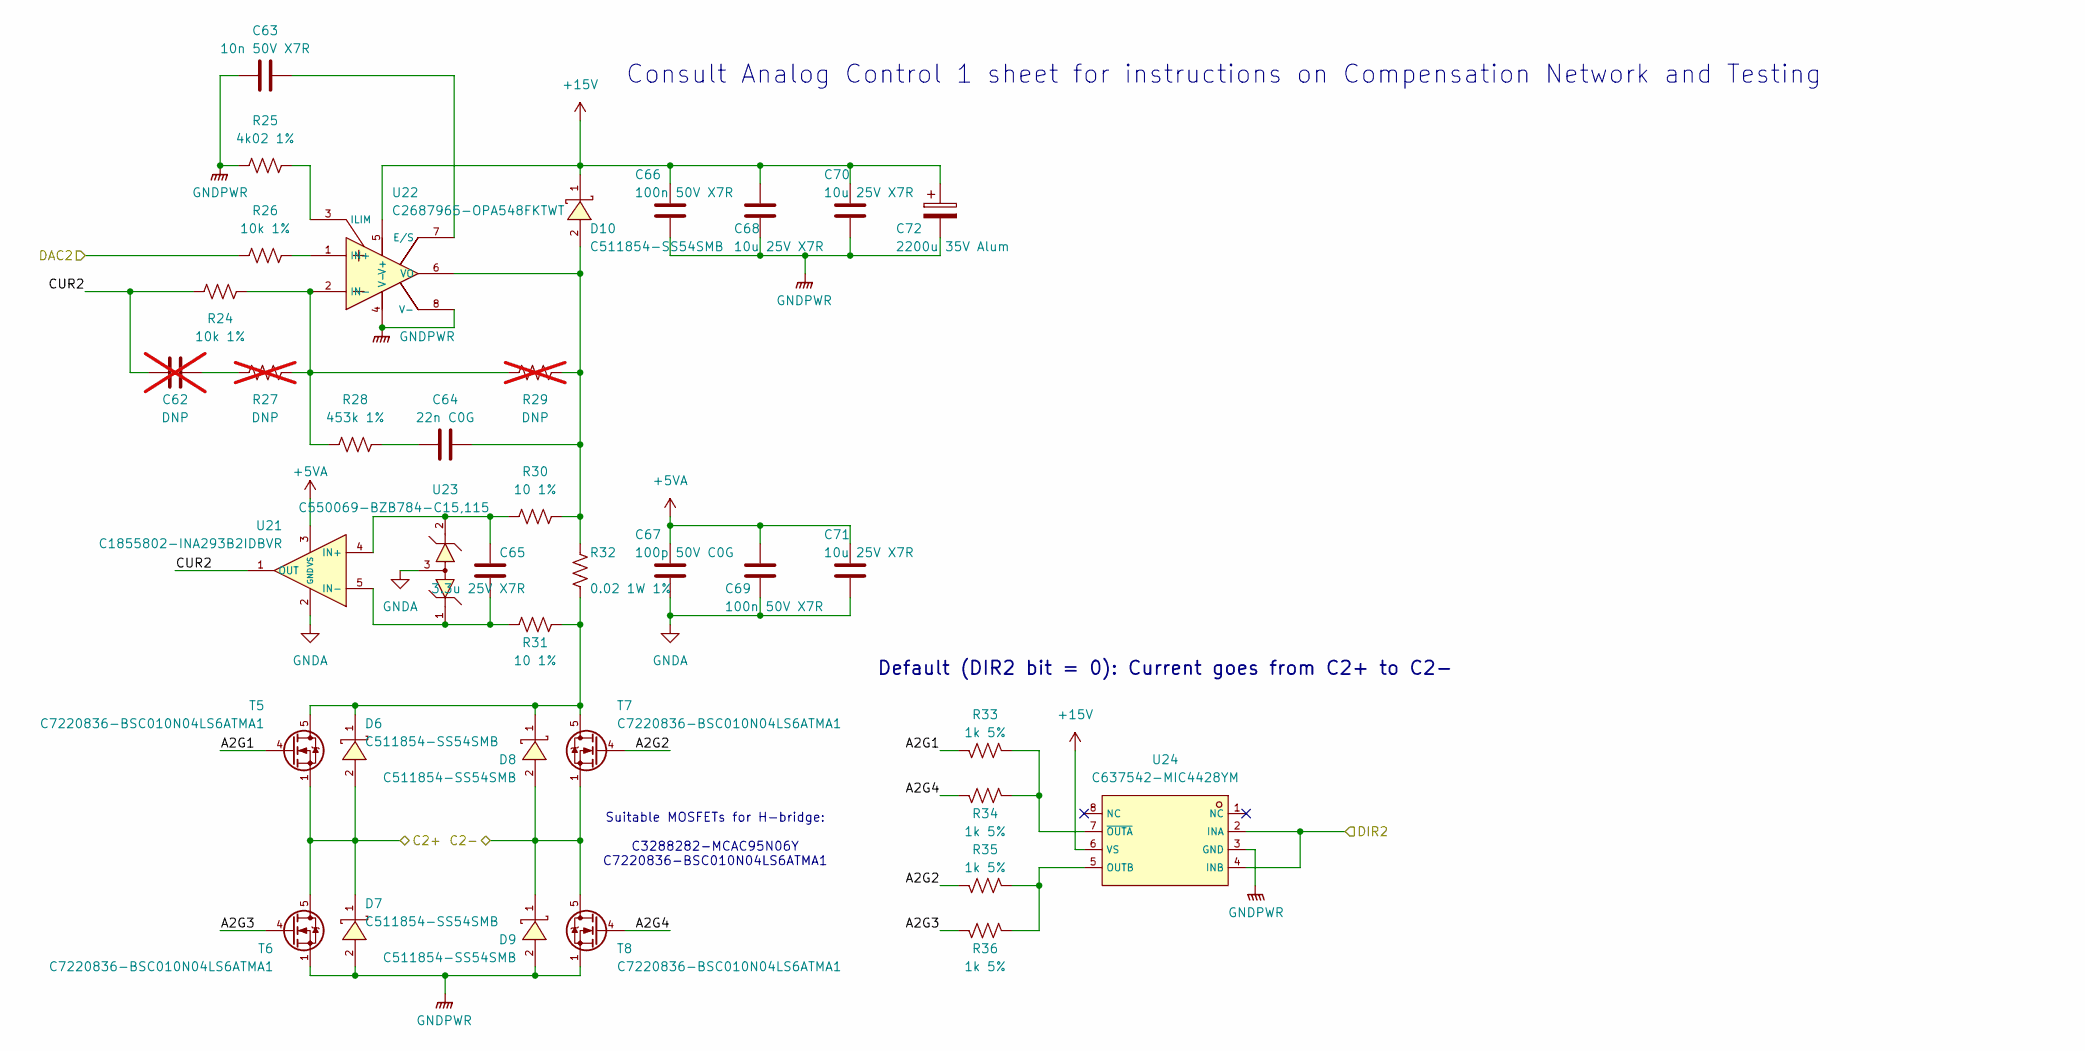
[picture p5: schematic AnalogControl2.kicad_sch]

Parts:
C62: DNP; C_0805_2012Metric; not fitted
C63: 10n 50V X7R; C_0402_1005Metric; LCSC C15195
C64: 22n C0G; C_0805_2012Metric; LCSC C2181592
C65: 3.3u 25V X7R; C_0805_2012Metric; LCSC C7393948
C66, C69: 100n 50V X7R; C_0402_1005Metric; LCSC C307331
C67: 100p 50V C0G; C_0402_1005Metric; LCSC C1546
C68, C70, C71: 10u 25V X7R; C_0805_2012Metric; LCSC C3039694
C72: 2200u 35V Alum; C3829879-CAP-SMD_BD16.0-L17.0-W17.0-LS18.0-FD; LCSC C3829879
D6, D7, D8, D9, D10: C511854-SS54SMB; C511854-SMB_L4.6-W3.6-LS5.3-RD; LCSC C511854
R24, R26: 10k 1%; R_0402_1005Metric; LCSC C2906861
R25: 4k02 1%; R_0402_1005Metric; LCSC C324800
R27, R29: DNP; R_0603_1608Metric; not fitted
R28: 453k 1%; R_0402_1005Metric; LCSC C3013172
R30, R31: 10 1%; R_0402_1005Metric; LCSC C138066
R32: 0.02 1W 1%; R_1206_3216Metric; LCSC C7420010
R33, R34, R35, R36: 1k 5%; R_0402_1005Metric; LCSC C2906899
T5, T6, T7, T8: C7220836-BSC010N04LS6ATMA1; C7220836-TDSON-8_L6.0-W5.0-P1.27-LS6.2-BL_1; LCSC C7220836
U21: C1855802-INA293B2IDBVR; C1855802-SOT-23-5_L2.9-W1.6-P0.95-LS2.8-BR; LCSC C1855802
U22: C2687965-OPA548FKTWT; C2687965-TO-263-7_L10.2-W8.9-P1.27-LS15.2-BL; LCSC C2687965
U23: C550069-BZB784-C15,115; C550069-SOT-323-3_L2.0-W1.3-P1.30-LS2.1-BR; LCSC C550069
U24: C637542-MIC4428YM; C637542-SOIC-8_L4.9-W3.9-P1.27-LS6.0-BL; LCSC C637542

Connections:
+5VA: C67.1, C69.1, C71.1, U21.3 (VS); also elsewhere on the board
+15V: C66.1, C68.1, C70.1, C72.1, D10.1 (K), U22.5 (V+), U24.6 (VS); also elsewhere on the board
/Analog Control 2/A2G1: R33.2, T5.4 (G)
/Analog Control 2/A2G2: R35.2, T7.4 (G)
/Analog Control 2/A2G3: R36.2, T6.4 (G)
/Analog Control 2/A2G4: R34.2, T8.4 (G)
/Analog Control 2/CUR2: C62.1, R24.1, U21.1 (OUT)
/Coil2+: D6.2 (A), D7.1 (K), T5.1 (S), T6.5 (D); also elsewhere on the board
/Coil2-: D8.2 (A), D9.1 (K), T7.1 (S), T8.5 (D); also elsewhere on the board
/DAC2: R26.1; also elsewhere on the board
/DIR2: U24.2 (INA), U24.4 (INB); also elsewhere on the board
GNDA: C67.2, C69.2, C71.2, U21.2 (GND), U23.3; also elsewhere on the board
GNDPWR: C63.1, C66.2, C68.2, C70.2, C72.2, D7.2 (A), D9.2 (A), R25.1, T6.1 (S), T8.1 (S), U22.4 (V-), U22.8 (V-), U24.3 (GND); also elsewhere on the board
unnamed: C62.2, R27.1
unnamed: C64.1, R28.2
unnamed: D6.1 (K), D8.1 (K), R31.1, R32.1, T5.5 (D), T7.5 (D)
unnamed: C64.2, D10.2 (A), R29.2, R30.1, R32.2, U22.6 (VO)
unnamed: C65.2, R30.2, U21.4 (IN+), U23.2
unnamed: C65.1, R31.2, U21.5 (IN-), U23.1
unnamed: C63.2, U22.7 (E/S)
unnamed: R25.2, U22.3 (ILIM)
unnamed: R26.2, U22.1 (IN+)
unnamed: R24.2, R27.2, R28.1, R29.1, U22.2 (IN-)
unnamed: R35.1, R36.1, U24.5 (OUTB)
unnamed: R33.1, R34.1, U24.7 (~OUTA)

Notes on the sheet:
Default (DIR2 bit = 0): Current goes from C2+ to C2-
Suitable MOSFETs for H-bridge: C3288282-MCAC95N06Y C7220836-BSC010N04LS6ATMA1
Consult Analog Control 1 sheet for instructions on Compensation Network and Testing

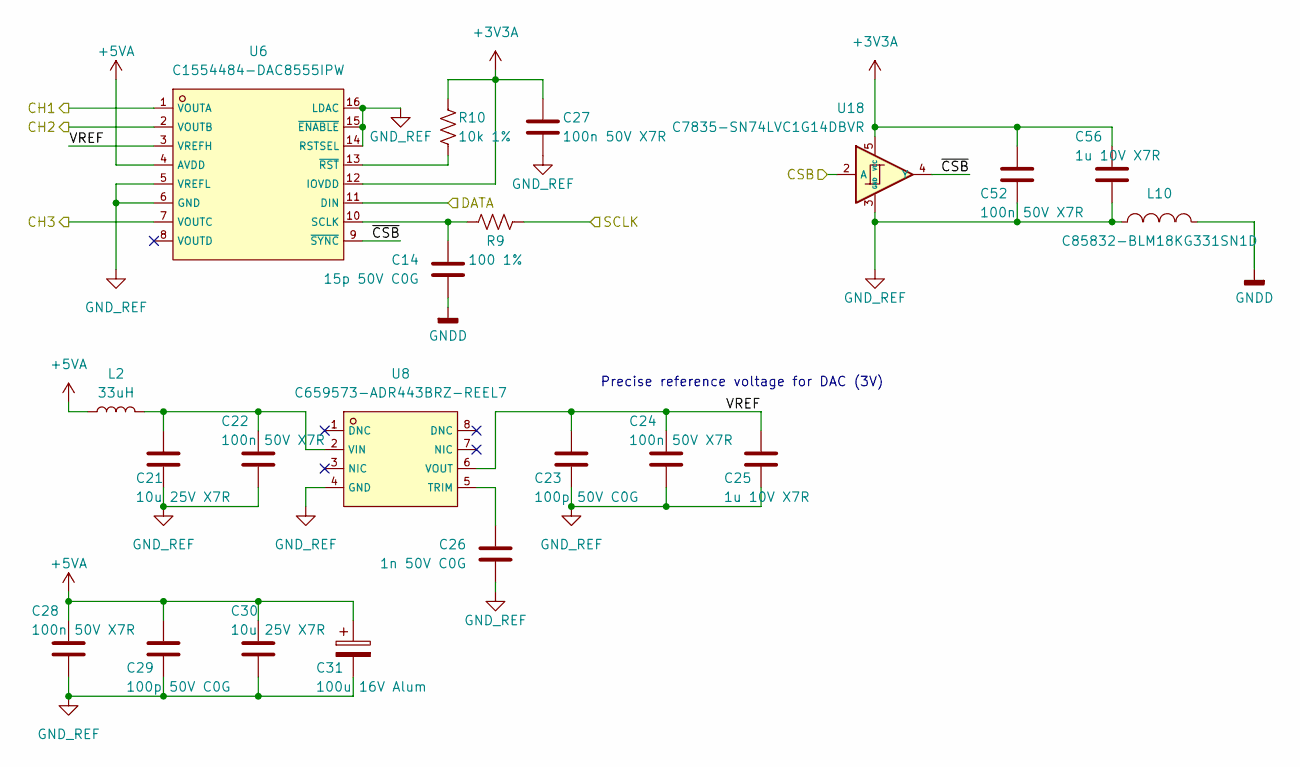
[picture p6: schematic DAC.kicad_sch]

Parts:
C14: 15p 50V C0G; C_0402_1005Metric; LCSC C880657
C21, C30: 10u 25V X7R; C_0805_2012Metric; LCSC C3039694
C22, C24, C27, C28, C52: 100n 50V X7R; C_0402_1005Metric; LCSC C307331
C23, C29: 100p 50V C0G; C_0402_1005Metric; LCSC C1546
C25, C56: 1u 10V X7R; C_0402_1005Metric; LCSC C7500381
C26: 1n 50V C0G; C_0402_1005Metric; LCSC C307441
C31: 100u 16V Alum; C37308-CAP-SMD_BD6.3-L6.6-W6.6-LS7.2-FD; LCSC C37308
L2: 33uH; L_0603_1608Metric; LCSC C5339211
L10: C85832-BLM18KG331SN1D; C85832-L0603; LCSC C85832
R9: 100 1%; R_0402_1005Metric; LCSC C25076
R10: 10k 1%; R_0402_1005Metric; LCSC C2906861
U6: C1554484-DAC8555IPW; C1554484-TSSOP-16_L5.0-W4.4-P0.65-LS6.4-TL; LCSC C1554484
U8: C659573-ADR443BRZ-REEL7; C659573-SOIC-8_L4.9-W3.9-P1.27-LS6.0-BL; LCSC C659573
U18: C7835-SN74LVC1G14DBVR; C7835-SOT-23-5_L3.0-W1.7-P0.95-LS2.8-BR; LCSC C7835

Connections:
+3V3A: C27.1, C52.1, C56.1, R10.1, U6.12 (IOVDD), U18.5 (VCC); also elsewhere on the board
+5VA: C28.1, C29.1, C30.1, C31.1, L2.1, U6.4 (AVDD); also elsewhere on the board
/CSB: U18.2 (A); also elsewhere on the board
/DAC1: U6.1 (VOUTA); also elsewhere on the board
/DAC2: U6.2 (VOUTB); also elsewhere on the board
/DAC3: U6.7 (VOUTC); also elsewhere on the board
/DAC/VREF: C23.1, C24.1, C25.1, U6.3 (VREFH), U8.6 (VOUT)
/DAC/~CSB: U6.9 (~SYNC), U18.4 (Y)
/SCLK: R9.2; also elsewhere on the board
/SDIO_0: U6.11 (DIN); also elsewhere on the board
GNDD: C14.2, L10.2; also elsewhere on the board
GND_REF: C21.2, C22.2, C23.2, C24.2, C25.2, C26.2, C27.2, C28.2, C29.2, C30.2, C31.2, C52.2, C56.2, L10.1, U6.5 (VREFL), U6.6 (GND), U6.14 (RSTSEL), U6.15 (~ENABLE), U6.16 (LDAC), U8.4 (GND), U18.3 (GND); also elsewhere on the board
unnamed: C14.1, R9.1, U6.10 (SCLK)
unnamed: R10.2, U6.13 (~RST)
unnamed: C26.1, U8.5 (TRIM)
unnamed: C21.1, C22.1, L2.2, U8.2 (VIN)

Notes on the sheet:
Precise reference voltage for DAC (3V)

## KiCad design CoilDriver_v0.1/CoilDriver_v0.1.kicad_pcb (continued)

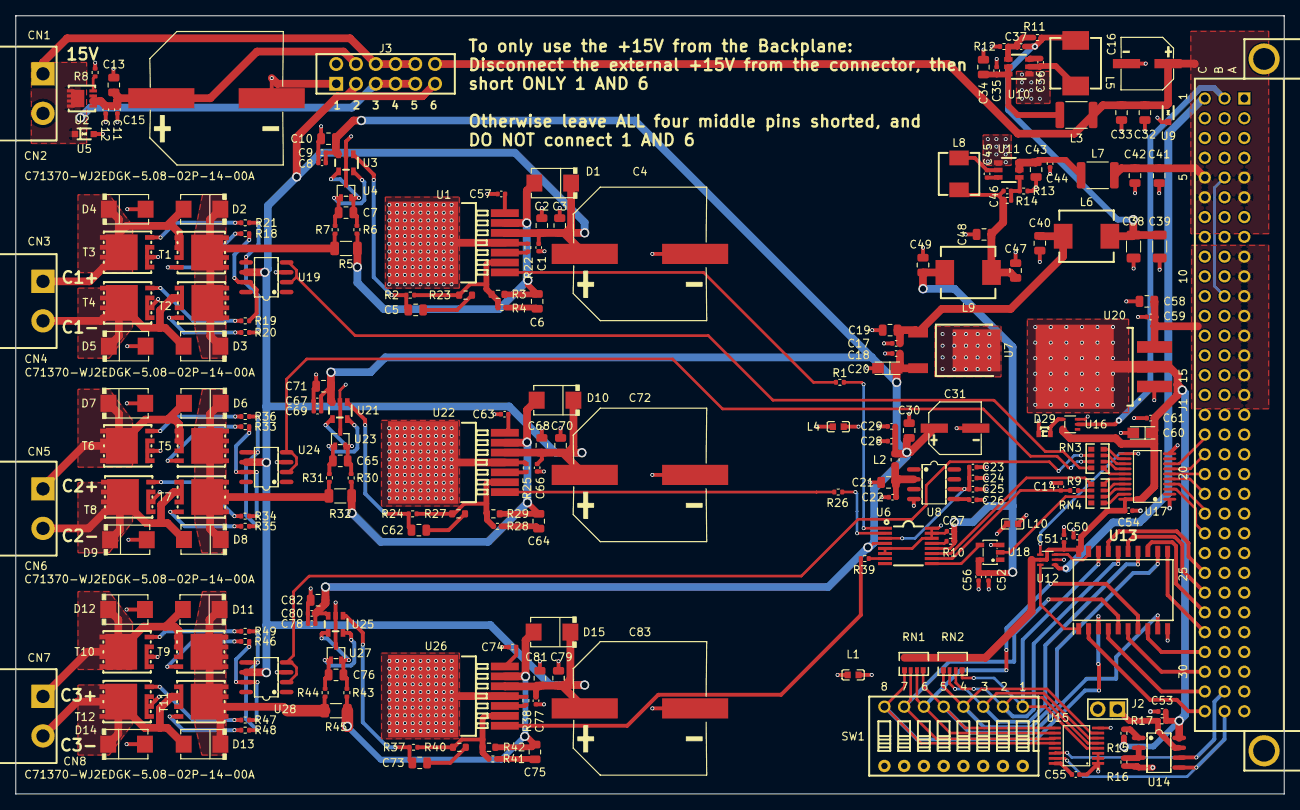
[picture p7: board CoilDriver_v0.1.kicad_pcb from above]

Board: 4 copper layers, 163.0 x 100.0 mm, 214 parts (0 on the bottom side), 139 nets.
